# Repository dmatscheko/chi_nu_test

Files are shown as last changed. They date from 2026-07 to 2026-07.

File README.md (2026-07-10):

# χ_ν coherent-matter lift test

A pre-registered, falsifiable test of the OPH **χ_ν "coherent-matter lift"** claim —
the mechanism behind the OPH hoverboard concept — together with the audit work
that maps what the OPH corpus actually proves. The aim is to fix exactly what the
theory predicts **before** any data is taken, build the minimal self-reading device
the prediction requires, and let a pre-agreed decision rule — not either side's
prior — settle the outcome (detect / null / mundane / undefined).

Path shortcuts used throughout (`OPH:/`, `HOVER:/`, `ANS:/`) are defined in
Document A; `ANS:/` now points at this repo's own [`communication/`](communication/)
directory.

## Layout

| Directory | What lives there |
|---|---|
| [`OPH_PROOF_CHAIN_HOLES.md`](OPH_PROOF_CHAIN_HOLES.md) | **The adversarial audit companion, two passes** — an independent hole inventory of the chain's interpretation layer (first pass F1–F19 against v5; second pass F20–F29 + per-finding disposition audits against v6.1; both passes independently *confirm* the formal layer by environment-level axiom sweeps). v6.1 adopted the first pass; **v7 closed both passes' mathematics by theorem** (T27/T28/T29 + F20/F25/F26 closures) and swept the second pass's residue ledger; disposition tables in the proof chain's §11. |
| [`OPH_PROOF_CHAIN_PAPER.md`](OPH_PROOF_CHAIN_PAPER.md) | **The expository paper** — the whole machine-checked proof chain written as ordinary mathematics: statement, proof, "why", and a plain-language paragraph per result. Adds nothing to the Lean tree (the tree is the authority); exists so a physicist can read the chain end-to-end without opening a `.lean` file. |
| [`test/`](test/) | **The physics test** — the pre-registration ledgers that govern the experiment. |
| [`proof_chain/`](proof_chain/) | **The minimal-proof-chain work** — what the OPH corpus proves (incl. the `formal/` Lean project that machine-checks it), the audit exchange with the OPH side, and the satellite-repo audits. |
| [`build/`](build/README.md) | **The hardware** — Milestone-1 self-reading piezo PoC (build plan, rev-2 electronics + schematics, jig, firmware) and the Stage-0 calibration results. |
| [`communication/`](communication/) | **The Q&A with the OPH side** (`ANS:/`) — questions, replies, and the OPH-side PDFs. Absorbed from the former sibling repo on 2026-07-06. |

## The physics test (`test/`)

| File | Role |
|---|---|
| [`DOCUMENT_A_prediction_ledger.md`](test/DOCUMENT_A_prediction_ledger.md) | **Start here.** Imports the OPH math with verified provenance, records the agreed OPH-side inputs, discloses the conservation-law priors, and derives the falsifiable predictions + decision rule. Governs the outcome on its own. |
| [`DOCUMENT_C_run_matrix_and_error_budget.md`](test/DOCUMENT_C_run_matrix_and_error_budget.md) | The instrument, the run matrix (R-pre, ABBA, ACTIVE±/SHAM, blind controls), the error budget that fixes the detection floor, and the energy-budget logging. |
| [`DOCUMENT_B_critique_ledger.md`](test/DOCUMENT_B_critique_ledger.md) | Open-questions & credit ledger. Two live items — the ΔS-estimator bridge (G9) and the energy ledger (G10) — plus the disposition of the original critique (mostly closed) and what stands regardless of any outcome. |

## The minimal proof chain (`proof_chain/`)

| File | Role |
|---|---|
| [`OPH_CORE_MINIMAL_PROOF_CHAIN.md`](proof_chain/OPH_CORE_MINIMAL_PROOF_CHAIN.md) | **v7.** The minimal proof chain for the core OPH idea: machine-checked (Lean) → paper-side theorems → conditional → asserted/calibrated — with the conservation-law bounds on the χ_ν chain. Background for all three ledgers. |
| [`formal/`](proof_chain/formal/) | **The Lean 4 project that machine-checks the chain** — 38 modules; 1284 non-internal theorem/def declarations swept at the environment level (v10 filter; earlier counts used a wider filter), 0 `sorry`, 0 custom axioms (incl. an attributed copy of the OPH core with its three `sorry`s discharged; the v7 modules closing the adversarial audit's mathematics; the v9 worldline/crawl theorems T36/T37; and the v10 campaign T38–T41: the parity splitting, two-power universality, the lone diagonal observer). See its [`README`](proof_chain/formal/README.md) and the statement-by-statement audit in [`RESULTS.md`](proof_chain/formal/RESULTS.md). |
| [`AUDIT_RESPONSE.md`](proof_chain/AUDIT_RESPONSE.md) | The OPH side's 2026-07-06 response to our audit: validity grading per gap + the July paper pass that answers it. |
| [`AUDIT_RESPONSE_REVIEW.md`](proof_chain/AUDIT_RESPONSE_REVIEW.md) | Our verification of that response: all pin-cites checked, the P-derivation code executed (two-P finding), three refinements (R1 feed-forward carrier, R2 falsifiers ≠ energy ledger, §P). |
| [`formal_audits/`](proof_chain/formal_audits/) | Raw audits of the `dula/` satellite repos (verdict: not proof-chain-relevant; one reusable artifact, since ported). |

## How it fits together

**test/A** — what the theory predicts and how the result is decided ·
**test/C** — how it is measured · **test/B** — what stays open and what stands ·
**proof_chain/** — the standing of every imported claim and the audit exchange ·
**build/** — the device that produces the self-read receipt A requires ·
**communication/** — the primary-source Q&A the ledgers cite as `ANS:/`.

Version history lives in git: v0.1 ledgers (2026-06-02/03), the correction
pass ("corrections pass 1"), the v0.2 rewrite (2026-07-05), the audit exchange
and proof-chain v2 (2026-07-06), the v3/v4 `formal/` campaigns — the whole
chain machine-proven in one tree (2026-07-06) — the v5 campaign closing
the remaining open mathematics, incl. the D3 finite modular core and one
ledger erratum (2026-07-07) — and the v6 campaign settling the stride
conjecture (T25, the coprimality classification of two-column screens,
with the mirror lemma and the quotient lift as new tools) plus the
expository paper `OPH_PROOF_CHAIN_PAPER.md`, audited against the Lean tree,
and the v6.1 response to the adversarial audit `OPH_PROOF_CHAIN_HOLES.md`
(T26 — the cosmological-constant step; the G10 pricing convention named;
the F18 erratum table applied; disposition in the proof chain's §11)
(2026-07-07) — and the v7 campaign closing both audit passes' mathematics
by theorem (T27 Route A assembled; T28 the real-time modular flow; T29 the
channel bridge; the F20/F25/F26 closures; the ℤ₆ group isomorphism; the
theorem-grade energy anchors; the F22 evidence artifacts; the F21 residue
sweep) (2026-07-07). The former
`communication/` sibling repo's own history remains at
https://github.com/dmatscheko/hoverboard-experimental-precursor.

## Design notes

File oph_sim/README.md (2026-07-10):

# OPH proof chain — the simulation showroom (v2)

An interactive companion to [`../OPH_PROOF_CHAIN_PAPER.md`](../OPH_PROOF_CHAIN_PAPER.md)
(corpus **v10**, 2026-07-10: 38 Lean modules, 1284 swept declarations, 0 `sorry`,
standard axioms only) — and, new in v2, a **research instrument** pointed at the
chain's one remaining open mathematics item (the arbitrary-subset
classification). Sixteen scenes: the machine-checked core simulated live, the
conditional tower with every named hypothesis on the label, and a frontier wing
whose experiments have already produced five machine-testable conjectures
(C1–C5, [`FINDINGS.md`](FINDINGS.md) Part IV).

## Run

ES modules need a server (any static server works):

```sh
python3 -m http.server 8123 --directory oph_sim    # from chi_nu_test/
# → http://localhost:8123
```

Headless (same engine, no browser):

```sh
node node/selftest.mjs          # the 38-check theorem cross-check battery
node node/experiments.mjs quick # frontier experiments (E1–E10) → data/experiments.json
node node/experiments.mjs all   # + the multi-minute exhaustive jobs
```

## The scenes

**The cylinder**
- **Holography 3D** — the Rule-90 spacetime block as a cylinder; timelike /
  lightlike / sloped (now a theorem: T36) / spacelike screens; theorem badge +
  live 𝔽₂ rank on every slider; decode animation (green = local propagation,
  violet = determined-but-global, now the theorem T30a); ghost seeds; **Route A
  assembled** (T27) with rank/random schedules, T32's universal termination on
  the label, and the audit's exact stall witness (n=3, t=2) as a button.
- **Worldline lab (T36)** — draw ANY observer path; 1-Lipschitz paths get the
  theorem (sharp threshold, closure complete — the fan animation is the
  induction of `inferable_fan_of_pairs`); superluminal paths get the honest
  open-territory treatment, the kernel-checked (6,2)/(8,3)/(10,4) walls, and
  the teleporting observer's permanent ghost.
- **The crawl (T37)** — the gap-2 closure staged live: enclosed middle column →
  pair fans fill row 1 → row-0 hops of two wrap the odd ring (the ring dial
  shows the crawl crawling); even rings keep row 0 half-dark with the
  checkerboard ghost; the full T30+T37 distance trichotomy; the violet exhibit.
- **Phase maps** — live-computed landscapes: the jewel's exact staircase
  n = 2(t+1) (all green: T30b), the stride×ring gcd pattern with the violet
  T30a country, and the T36 worldline-invariance map (no deviations, by
  theorem).

**The open frontier**
- **Screen lab** — build arbitrary subsets; live rank/kernel/ghosts/closure;
  the **shadow atlas** (maximal ghost zero-sets = the classification itself)
  with the C1 even-ring parity law and C2 odd-ring rigidity checked live;
  Monte Carlo against the random-matrix baseline.
- **Beyond Lipschitz** — the recorded experiment suite (E1–E10): exhaustive
  capacity sweeps t ≤ 6, the power-of-two universality (C3, with the u-adic
  proof sketch), the teleport permanent-ghost law (C4), kink/slope-2/slack
  families, Lipschitz surjectivity (C5), tight-subset censuses — with live
  re-verification buttons that re-run the walls in your browser.

**Foundations** — Consensus (T0–T4, T12: Φ descent, the two-clerk race,
protection = Route A) and Toys (T5 width-3 witnesses, T8 layered sweep).

**The tower** (machine-checked mathematics downstream of named hypotheses) —
Hexacode (T19/T22, all enumerations live), Thermal time (T21/T28/T33 with the
KMS boundary strip drawn numerically), Dark sector (T15 with the exact Lean
phantom profile M_A, ρ_A), Collar & cage (T16/T35/T11/T10/T24 + the T29
channel-composite law computed live), Hypercharge & ℤ₆ (T13 in exact
rationals; the ℤ₆ wheel), Quorums (T23, the 3f+1 boundary).

**Meta** — The map (the graded ladder, scene↔theorem table, where mathematics
ends, the feedback-loop record) and Self-tests (the full battery in-browser).

## Fidelity contract

- One engine (`js/lib/f2.js`, `rule90.js`, `exact.js`) serves every scene, the
  battery, and the headless experiments. Definitions are transliterated from
  the Lean tree (`Inferable`'s exact rules, `colFamily`/`gapTube`/`slopeTube`/
  `pathScreen`, `ringDist`, the T24/T11 interval brackets, HexacodePort's 𝔽₄
  tables, Hypercharge's constraints in exact rationals).
- Every theorem badge is paired with an independent live computation; the
  38-check battery (`node/selftest.mjs` = Self-tests scene) is the acceptance
  gate. 38/38 at build time, in node and in the browser — five checks are
  anchored to the v10 theorems this simulation's own findings became
  (T38–T41; FINDINGS.md Part V).
- Discrete math is exact (bitmask/bitset 𝔽₂; int path n ≤ 30, Uint32Array
  beyond). Real-valued scenes use doubles against Lean's interval brackets.
- Part III/IV scenes simulate mathematics *inside* named hypotheses (SEE, MAR,
  L0–L7, D3, G9, G10…), never physics from consensus (T7's fence). The χ_ν
  experiment's expected outcome, per the chain's own grading: **NULL**.

## Files

```
index.html            the showroom shell (sidebar, stage, panel, banner)
js/app.js             scene registry / lazy router
js/lib/               f2.js · rule90.js · exact.js · ui.js · selftest.js
js/wing3d.js          the three.js wing (7 scenes)
js/scenes/            worldline · crawl · phase · subsetlab · frontier ·
                      hypercharge · qbft · selftest · map
node/                 selftest.mjs · experiments.mjs (headless drivers)
data/experiments.js(on)  the recorded frontier results (E1–E10)
three.min.js          three.js r147 (MIT, bundled)
```

See [`FINDINGS.md`](FINDINGS.md) for everything the simulation has taught the
theory so far — Parts I–III (v1: the items that became T30, T31, T36, T37) and
Part IV (v2: the shadow-atlas laws, power-of-two universality, the permanent
ghost, and the conjecture list C1–C5 handed to the next formal campaign).

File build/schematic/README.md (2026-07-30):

# Schematic generator

`schematic.py` turns a compact **path-based** text netlist into a real
electronic schematic SVG — proper symbols in **US/ANSI or IEC/European
style**, obstacle-avoiding orthogonal autorouting, automatic junction dots,
and **auto-sized sheets** (leave the size off `sheet` and the canvas fits
itself around the drawing, title and notes included). Zero dependencies
(pure Python 3).

The core idea: **the route is the statement.** Wires are written as `->`
paths, parts sit inline *on* the paths, and named nodes form junctions:

```
LEDC.p -> [res Rb "R_base" "1k"] -> BASE
BASE -> up 72 -> [npn Q1 "Q1" "S8050"].B
Q1.E -> OUT <- Q2.E
OUT -> [res Rd "100 Ω"] -> [piezo RING "Ring 0"] -> GND
```

Everything can be pinned manually (`at`, `right 120`, `(x,y)` waypoints) —
but nothing has to be: `at` is optional even for standalone parts and chips
(the first wired pin places them), statement order is free (whatever cannot
resolve yet is retried once the whole file is read), a sheet with no
absolute coordinates at all seeds itself at the origin, and with no hints
placement advances along the path while the router finds a clear Manhattan
route. Full reference: **[LANGUAGE.md](LANGUAGE.md)**.
One-of-every-symbol galleries: [examples/symbols_us.sch](examples/symbols_us.sch)
and [examples/symbols_iec.sch](examples/symbols_iec.sch) (same kit, both styles).
The previous (v1) engine, sources, and SVGs live in git history (the `v1/`
snapshot was removed from the working tree in the July 2026 cleanup).

The build diagrams are generated from the `.sch` sources here:

| Source | Output (in `../`) |
|---|---|
| `stage0_characterization.sch` | Stage-0 piezo characterisation rig (gen + scope) |
| `drive_stage.sch` | push-pull TX drive buffer |
| `tx_select.sch` | CD4066 TX-select (Stage 1b, full 3×3) |
| `peak_detector.sch` | RX Schottky envelope detector |
| `controller_power.sch` | power tree + I²C bus |
| `system_overview.sch` | block/flow diagram |
| `system_connected.sch` | whole instrument as one connected block graph |
| `full_instrument.sch` | full instrument as one real schematic, **built from the parts**: `import`s `drive_buffer` (drive_stage), `CD4066` (tx_select), `rx_channel` ×3 + `vbias` (peak_detector) |

## Regenerate

The canonical SVGs live in `../` (next to `electronics.md`, which embeds
them). The Makefile writes there:

```sh
make            # build all ../*.svg from the .sch sources
make png        # also drop ../*.png previews (needs rsvg-convert)
make nets       # per-net colour debug views -> ./*_nets.svg (never into ../)
make kicad      # KiCad 9 schematics + symbol library -> ./kicad/
make cleanup    # rewrite the .sch: drop params that don't change the SVGs
make clean      # remove the PNG previews, *_nets.svg and ./kicad/
```

By hand — every mode takes any number of `.sch` files (`make` is just the
first line); with several inputs `-o` names a directory:

```sh
python3 schematic.py *.sch -o ../
python3 schematic.py drive_stage.sch -o ../drive_stage.svg
```

## KiCad output (`--kicad`)

The same sheets also compile to a **real KiCad 9 schematic** — not a picture of
one: `--kicad` writes `<sheet>.kicad_sch` with every symbol it uses embedded in
the file, plus those symbols as a standalone `schpy.kicad_sym` library next to
it (so they can be picked from KiCad's own symbol browser and re-used by hand).

```sh
python3 schematic.py full_instrument.sch --kicad      # -> full_instrument.kicad_sch
python3 schematic.py *.sch -o kicad/ --kicad          # all of them + schpy.kicad_sym
make kicad
```

Open the `.kicad_sch` with KiCad's Schematic Editor (it offers to create a
project around it), or drop it into an existing project *under that project's
name* — `MILESTONE_1_build/MILESTONE_1_build.kicad_sch` — and it opens as that
project's root sheet. Nothing else is needed: no library has to be installed,
because the symbols travel inside the file.

**It really connects.** 10 px become 1.27 mm — KiCad's 50 mil grid, which is
also the raster these symbols were drawn on, so a resistor lead lands on
±3.81 mm exactly like KiCad's own `Device:R`. Three things make the connections
hold:

* **Snapped before routing.** The sheet is re-laid-out with parts, nodes and
  chip pin rows snapped onto the 50 mil raster *before* the autorouter runs, so
  the schematic lands on KiCad's grid and stays editable — drag a symbol and
  its wires come along. Snapping is a function of the coordinate, so equal
  coordinates stay equal and every row, column and alignment survives. If a
  sheet is drawn finer than that, the exporter falls back through 25 → 12.5 →
  5 → 2.5 mil until the circuit comes out **exactly** as the SVG draws it — the
  netlists are compared, and a sheet that cannot be reproduced is an error, not
  a silent rewiring. The grid it settled on is printed with each file.
* **Exact arithmetic.** Every coordinate is quantised to half a pixel before
  scaling, which makes each millimetre value an exact 4-decimal number, so a
  pin's absolute position (symbol origin + pin offset, the way KiCad adds them
  up) is bit-identical to the wire end drawn on it.
* **A real wire graph.** The routed polylines are re-cut before they are
  written: split at every point where another wire ends or a pin sits,
  overlapping duplicates dropped, junction dots where three or more segments
  meet, hair-off-axis runs pulled straight. KiCad joins wires at shared
  endpoints, not by "they look like they touch".

The result: **the netlist KiCad reads back is the netlist `--nets` prints**,
pin for pin — checked with `kicad-cli sch export netlist` on every sheet here.

What carries over:

| `.sch` | KiCad |
|---|---|
| `res`, `cap`, `diode`, `npn`, `opamp`, … | symbols in the embedded `schpy` library (`schpy:R`, `schpy:Q_NPN_BCE`, … — KiCad's own names and pin numbering, so swapping in `Device:R` later keeps the pins) |
| part `ref` + label / value | `R1` / `100 Ω` (auto designators; the source name is kept in a hidden `Sch` property, the label in `Description`) |
| `net GND`, `net +3.3V`, rail/gnd terminals | power symbols — one per terminal, all on the named net |
| `node NAME` | a net label on the wire (`_`-names stay plumbing, as in `--nets`) |
| `port` | a global label |
| `chip` / `block` | a per-sheet symbol: box, named pins, pin numbers 1..n in declaration order |
| `note` | text block under the drawing; `sheet` title → title block |
| `flow` arrows (system diagrams) | plain graphic polylines — they are drawings, not nets |

### Footprints

Every standard part gets a default footprint from KiCad's own libraries, so the
netlist is ready for the PCB step without a round of field-filling:

| part | footprint |
|---|---|
| `res` | `Resistor_SMD:R_1206_3216Metric` |
| `cap` | `Capacitor_SMD:C_1206_3216Metric` |
| `cap_pol` | `Capacitor_Tantalum_SMD:CP_EIA-3216-18_Kemet-A` (EIA-3216 = 1206) |
| `inductor` | `Inductor_SMD:L_1206_3216Metric` |
| `diode` `schottky` `zener` | `Diode_SMD:D_1206_3216Metric` |
| `led` | `LED_SMD:LED_1206_3216Metric` |
| `npn` `pnp` `nmos` `pmos` | `Package_TO_SOT_SMD:SOT-23` |
| `opamp` | `Package_SO:SOIC-8_3.9x4.9mm_P1.27mm` |
| `xtal` | `Crystal:Crystal_SMD_2012-2Pin_2.0x1.2mm` |
| `testpoint` | `TestPoint:TestPoint_Pad_D1.5mm` |
| `piezo` `battery` `switch` `button` `pot`, `chip`, `block` | left empty — those are the custom / mechanical ones (the rings, the LiPo, the modules) |

Override any of them per part with **`fp "Lib:Footprint"`**, which works on
standalone parts, inline parts, chips and `defchip` types alike:

```
res Rsda "Rp" "4.7 kΩ" fp "Resistor_SMD:R_0805_2012Metric" at 300,80
DRVOUT -> [res Rdd "R_drive" "100 Ω" fp "Resistor_THT:R_Axial_DIN0207_L6.3mm_D2.5mm_P10.16mm_Horizontal"] -> SW.INB
chip SW CD4066 fp "Package_SO:SOIC-14_3.9x8.7mm_P1.27mm" at DRVIN +460,0
```

The default also lands in the generated `schpy.kicad_sym`, so a symbol picked
from that library by hand arrives with its footprint already set.

The instrument's own parts carry their package in the `.sch` next to the
circuit, so the netlist is complete without touching KiCad:

| part | footprint | declared in |
|---|---|---|
| CD4066 | `Package_SO:SOIC-14_3.9x8.7mm_P1.27mm` | the `defchip` in `tx_select.sch` — every instance inherits it |
| ADS1015 | `Package_SO:TSSOP-10_3x3mm_P0.5mm` (TI's DGS body) | each sheet that draws it |
| MCP6022 ×3 | `Package_SO:SOIC-8_3.9x4.9mm_P1.27mm` | the `package AMP` line in `peak_detector.sch` |
| Xiao ESP32-C6 | `Seeed_Studio_XIAO_Series:XIAO-ESP32-C6-SMD` | `full_instrument.sch` (Seeed's own library; add the `.pretty` to KiCad's footprint table) |
| ring 0..2 | `Connector_JST:JST_PH_B2B-PH-K_1x02_P2.00mm_Vertical` | `peak_detector.sch` / `drive_stage.sch` — the two ring wires plug into the board |
| 1S LiPo | `Battery:BatteryHolder_MPD_BH-18650-PC` | `controller_power.sch`, `full_instrument.sch` |

`stage0_characterization.sch` has none: it is a bench rig (generator, scope
probes, loose rings), not a board.

### Real pin numbers and multi-unit packages

A generic symbol knows nothing about its package, so by default pins are
numbered 1..n in the order the symbol declares them. Two keywords fix that,
and neither changes the SVG:

* **`pins "…"`** gives the real package pin numbers, either by name
  (`pins "in+=3 in-=2 out=1 vcc=8 vee=4"`, the sheet's pin names or the KiCad
  symbol's, whichever reads better) or positionally (`pins "3,2,1,8,4"`). On a
  `defchip` it applies to every instance of that type.
* **`unit PKG [A]`** says this part is one unit of the physical package `PKG`
  (a name in the current namespace, so a `def` stamped three times gives three
  packages). Units of one package share a designator, a footprint and one
  multi-unit KiCad symbol — KiCad shows them as `U1A`, `U1B`. The optional
  letter fixes the order.
* **`package PKG "Device" [fp "Lib:Footprint"]`** names the physical part the
  units share (KiCad `Value`) and its footprint.

That is how the two `½ MCP6022` amplifiers in `peak_detector.sch` become one
SOIC-8 with the datasheet's pinout, while still being drawn as two op-amp
triangles in both the SVG and KiCad:

```
opamp A1 "A1 ½ MCP6022" "x21"  unit AMP A pins "in+=3 in-=2 out=1 vcc=8 vee=4" …
opamp A2 "A2 ½ MCP6022" "x5.7" unit AMP B pins "in+=5 in-=6 out=7 vcc=8 vee=4" …
package AMP "MCP6022" fp "Package_SO:SOIC-8_3.9x4.9mm_P1.27mm"
```

A unit's own value (`x21`) travels in a visible `Note` field, since KiCad's
`Value` belongs to the whole package. `tx_select.sch` and `full_instrument.sch`
carry the CD4066 and ADS1015 pinouts the same way (taken from KiCad's own
`4xxx` and `Analog_ADC` libraries).

Without `pins`, *Update PCB from Schematic* warns `No net found for component
U1 pad N (no pin N in symbol)` for every package pad the sheet does not draw —
which is also the honest warning for pins that really are unused (the CD4066's
fourth switch, the ADS1015's `AIN3`/`ALERT`, the Xiao's spare GPIOs). Declare
those pins in the `chip` block if you want them silent and reachable.

Two things are deliberately *not* claimed: there are no footprints (the
`Footprint` field is empty — that is the PCB step's job), and ERC will report
`power_pin_not_driven` for every power net, because nothing in a generated
sheet is a power *source*. Add a `PWR_FLAG` on each rail in KiCad, or silence
that rule, as usual. ERC also notes `lib_symbol_issues` until `schpy.kicad_sym`
is added to the symbol library table (Preferences → Manage Symbol Libraries),
and `endpoint_off_grid` on sheets that had to fall back to a finer grid —
harmless, the connections there are exact; set KiCad's grid to the size the
export reported and editing is comfortable again.

## Why a netlist instead of hand-drawn SVG

Every path endpoint is a **named pin** (e.g. `Q1.E`, `ADS.AIN0`). If a path
references a pin that does not exist, the tool **errors out** — so "do all
the paths connect?" is checked mechanically on every build. The diagrams are
also diffable and re-generatable, unlike hand-placed `<line>`s. Repetition is
first-class: a `def` block stamps a whole sub-circuit per `use`, and
`import "file.sch" [NAME …]` pulls just the `def`/`defchip` definitions out
of another sheet (its own drawing is skipped) — so every detail sheet doubles
as a library. `full_instrument.sch` contains no redrawn circuitry at all: it
imports the drive buffer from `drive_stage.sch`, the CD4066 from
`tx_select.sch`, and the amp+detector channel (stamped ×3 around one shared
bias divider) from `peak_detector.sch`.

## Colouring nets

1. **Meaningful colours (normal render):** declare a net colour once —
   `net GND #2166ac` — and end paths at its terminal (`-> GND`, `-> +5V`).
   The whole electrically-connected net inherits the colour. The build
   diagrams use +5 V `#e8412f`, +3.3 V `#a31515`, GND `#2166ac`, signals
   black. (For a coloured net without a terminal, put `color #hex` at the
   end of one of its paths.)
2. **Debug view (`--color-nets`):** auto-assigns a *distinct* colour per net,
   overriding everything — so a net showing two colours is broken and two
   nets sharing a colour are an accidental short:

```sh
python3 schematic.py controller_power.sch --color-nets   # -> controller_power_nets.svg
make nets
```

3. **Netlist print (`--nets`):** prints each electrical net as one sorted line
   (`REF.PIN` members, `<NET>` terminals, `(NAME)` nodes). Layout-independent —
   `diff` it before/after a re-layout to prove the electronics didn't change:

```sh
python3 schematic.py drive_stage.sch --nets
```

4. **Cleanup (`--cleanup`):** rewrites the given `.sch` files in place, deleting
   every position / path-length parameter (`at` clauses and offsets, exact
   moves, bare direction elements, aligned-move offsets) whose removal keeps
   the rendered SVG of **every** given sheet byte-identical — proof that the
   parameter was dead weight. Always pass the whole family so `def`s imported
   across files stay protected (that is what `make cleanup` does):

```sh
python3 schematic.py --cleanup *.sch
make cleanup
```

A net is the set of wires that electrically touch (coincident endpoints or
T-junctions). Plain crossings don't touch — a wire crossing another with no
dot keeps its own colour, visual proof it's a no-connect. The colour views
write to `*_nets.svg` *here* (never into `../`).

## Language cheat-sheet

See [LANGUAGE.md](LANGUAGE.md) for the full reference. The essentials:

```
sheet 1050x800 "Title"                  # canvas; note …  adds footnotes
sheet "Title"                           # no size -> auto-size, content centred
sheet "Title" iec                       # IEC/European symbols (default: us)
net +5V #e8412f "+5 V"                  # net colour + rail label, once

port DRV "Drive buffer OUT"             # no `at`: placed by its first wired use
chip T1 NE555                           # works for chips/blocks too
res  Rref "R_ref" "1 MΩ" a at RING.b +40,0 down   # or placed BY pin a, vertical
res  Rp "4.7 kΩ" fp "Resistor_SMD:R_0805_2012Metric"   # KiCad footprint override
rail F1 "+5V" at 300,80                 # standalone net terminal (label = net)
gnd  G1 at 300,400                      # same for ground (net GND)

DRV.p -> [res Rd "100 Ω"] -> SW.INB     # parts live ON the route
RING.b -> right 40 -> down -> [res Rr "1 MΩ"] -> down 30 -> GND   # hang + ground
Q1.E -> OUT <- Q2.E                     # runs meet: node at the midpoint + dot
[npn Q1].B -> BASE <- [pnp Q2].B        # pair-meet: spreads ±80 around the node
GPIO6 -> right to Rsda.b -> _SDA -> SDA # thread node _SDA into the line …
Rsda.b -> _SDA                          # … and tap it by name (preferred)
(382,85) -> (1250,85)                   # a bus (waypoints are literal)
Rsda.b -> down 68                       # tap down ONTO a line below (sketch)
Ra.b -> right to XIAO.V5 +50            # aligned tap: right only, to V5's x +50

chip ADS at 740,250 200x180 "ADS1015" "I²C 0x48"   # or defchip + include
  left  AIN0 AIN1 AIN2 AIN3
  right VDD SDA SCL
end

def channel(hot, ring)                  # define once …
  hot -> down -> [piezo RNG ring lpos left] -> down 40 -> GND
end
use channel ch0(H0, "Ring 0")           # … stamp: parts become ch0.RNG, …
node OUT                                # declare (unplaced) so a use can bind it
import "peak_detector.sch" rx_channel   # defs/defchips only, sheet skipped

block XIAO "Xiao ESP32-C6" "l1|l2" at 500,100 200x96 accent   # system diagrams
  bottom DRIVE RESET I2C
end
flow XIAO.DRIVE -> down -> BUF.e "DRIVE (GPIO2)" dash
```

Pin names by type:

| Type | Pins |
|---|---|
| `res` `cap` `cap_pol` `inductor` `piezo` `xtal` `switch` `button` | `a` `b` |
| `pot` | `a` `b` `w` (wiper) |
| `diode` `schottky` `zener` `led` | `a` (anode) `k` (cathode) |
| `npn` | `B` `C` `E` — `pnp`: `B` `E` `C` |
| `nmos` `pmos` | `G` `D` `S` |
| `opamp` | `in+` `in-` `out` `vcc` `vee` |
| `battery` | `+` `-` (aliases `a` `b`) |
| `gnd` / `rail` / `port` / `testpoint` | `p` |
| `chip` / `block` | the pins you declare (`block` also: `n s e w c`) |

Orientation words `up/down/left/right` set a part's a→b axis; `mirror` flips
it; `lpos up|down|left|right` moves the label. Junction dots appear only
where ≥3 conductor directions meet; plain crossings get **no** dot. Autorouted
wires leave/enter each pin with a straight 10 px run along the pin's direction
(`escape N` adjusts it; 0 disables).

Node naming: plain names (`BASE`, `OUT`) are circuit signals and appear in
`--nets`; a leading underscore (`_SDA`, `_V33`) marks a pure trace point —
hidden from `--nets` like the tool's own anonymous nodes, and never
confusable with a part ref or a net terminal.

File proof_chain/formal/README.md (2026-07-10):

# `formal/` — machine-checked closure work for the OPH minimal proof chain

| | |
|---|---|
| Date | 2026-07-06 (v3 + v4 campaigns) + 2026-07-07 (v5 + v6 + v7 + v8 campaigns) + 2026-07-09 (v9 campaign) + 2026-07-10 (**v10** campaign) |
| What | A standalone Lean 4 + Mathlib project that (v3) formalized the `OPH_CORE_MINIMAL_PROOF_CHAIN.md` §7 targets and the "open jewel", (v4) **absorbed the OPH Lean core itself into this tree with its three `sorry`s discharged** and formalized the remaining mathematically-formalizable links: the L2.4 algebra (hypercharges + ℤ₆), the D5 Einstein-branch algebra, the dark-sector mathematics (L2.7/L2.8 + the L2.11 FTC step), the collar-gate skeleton (L2.6), the ΔS-bridge definition side (P5/L2.12), the §7.6 stretch item (general Rule-90 decodability: boost invariance + the parity obstruction), and the hexacode MDS toy (§9), and (v5) **settled the odd-cylinder gap-2 threshold** (the §7.6 item v4 left open — the complete parity classification), **built the D3 finite modular core** (retiring "the one link with no isolable finite-mathematics core"), closed the hexacode weight distribution, machine-checked the run-matrix conversion constants (finding and fixing one ledger erratum), and formalized the corpus appendix's QBFT safety theorem (finding a boundary caveat), and (v6) **settled the stride conjecture** — T25, the coprimality classification of two-column screens (`gcd(g,n) = 1 ∧ n ≤ 2(t+1)` ⟺ capacity), via the new mirror lemma and quotient lift — plus the separation-statement clauses and the `EdgeRepairable`-strictness witness, and (v7) **closed the adversarial audit's remaining mathematics**: T27 — Route A *assembled* (local tube-preserving transactional decode-repair + `H_B` + the sharp `H_fib` jointly on the T9′ carrier, with both impossibility negatives and the stall witness machine-checked, closing F2); T28 — the real-time modular flow (`H = −log ρ` exists; `σ_z` is a ⋆-automorphism group with the textbook KMS boundary condition; `σ_i = Δ_ρ`; Hamiltonian-implemented uniqueness `e^{−K} = c·ρ`, closing F9 finite-dimensionally); T29 — the channel bridge (one indexed family, both counters, composite Tier-B1 law, closing F11); the ℤ₆ kernel as a **group isomorphism** (F10c); and the theorem-grade energy anchors bracketing the G10-convention (F15). **The whole chain lives, machine-proven, in this one directory tree.** The **v8 campaign** (same day, verification pass + simulation feedback + leftovers): independently re-verified the v7 modules (read + build + 1199-declaration environment sweep), then closed T27's named leftover — **T32, arbitrary-schedule termination** (`decodeStep_wellFounded`: the decode dynamics is strongly normalizing under EVERY scheduler; the rank stratification itself is the lexicographic potential) — and T28's named leftover — **T33, Skolem–Noether for the matrix algebra** (`algEquiv_matrix_inner`: every `ℂ`-algebra automorphism is inner; `kms_algEquiv_structure`: any KMS-satisfying automorphism IS the modular map with conjugator `c·ρ`) — plus the F24 residue — **T35, `TriangulatedSphere`** (the twelve-port count's three assumed equations are now theorems of an actual surface structure; kernel-checked icosahedron instance) — and two theorems surfaced by the simulation companion (`oph_sim/FINDINGS.md`): **T31, the readout trichotomy** (`readout_trichotomy` + `tubeData_surjective_iff`: ghosts/bijective/unrealizable split exactly at the threshold — above it EVERY tube reading is realizable, at it the readout is a bijection, below it empty fibers exist ⟺ `n < 2(t+1)`; Route-A corollaries `exists_unrealizable_tube_iff`, `no_stall_at_threshold`) and **T30, the local-decodability phase boundary** (`spread_screen_inferable_iff`: screens with pairwise column distance ≥ 3 admit ZERO local constraint-propagation inferences at any horizon; `adjacent_closure_complete`: the adjacent tube's propagation closure is the whole block at the sharp threshold; `violet_exhibit`: `n=8, g=3, t=3` is machine-checked as determined-but-locally-dark). **T34-lite**: the sloped-screen *definition* is now formal (`slopeTube`, floor convention, provably slope-0 = T9's tube), the failure half is a theorem at every slope, and slopes 1/2, 1/3, 2/3 have kernel-checked threshold instances — the general positive half remained the named open conjecture. The **v9 campaign** (2026-07-09) closed it: **T36 — the Lipschitz worldline theorem** (`Rule90Lipschitz.lean`): every 1-Lipschitz worldline pair-screen is *completely locally decodable* at the sharp threshold (`pathScreen_closure_complete` — T30b extended from the static observer to every causal worldline, zigzags and negative slopes included), hence an information set **iff** `n ≤ 2(t+1)` (`pathScreen_isInformationSet_iff`); corollary `slopeTube_isInformationSet_iff` — **the slope conjecture (holes-audit F6) is CLOSED**, every rational slope `0 ≤ p/q ≤ 1`, every `n`, `t`, base point, sharp. The non-Lipschitz regime is machine-checked to be genuinely wild (complete order-sensitive classification at `(6,2)` — `pairScreen_class_6_2`; all `8^4` paths decode at `(8,3)`; the slope-2 line and late jumps FAIL at exact capacity at `(10,4)`), which is the precise delimitation of the one remaining open mathematics item (arbitrary subsets). And **T37 — the gap-2 crawl classified** (`Rule90Crawl.lean`): T30's named leftover closed — on odd rings at the sharp threshold the distance-2 screen's propagation closure is the entire block (the simulation's crawl, made into a proof through T36's general fan with *inferred* anchors), on even rings it never reaches the seed row; with T30, local decodability of two-column screens is classified at every ring distance. The **v10 campaign** (2026-07-10, driven by the `oph_sim` v2 findings): **T38 — the parity splitting** (`Rule90Parity.lean`): finding R1 formalized — on even rings the spacetime block is two non-interacting Rule-60 sectors (with the bridge `traj x i j = rule60^[2i] x (j−i)` and the half-ring conjugacy `sectorTrace_succ`), and an ARBITRARY cell set fails ⟺ a nonzero single-parity ghost is dark (`not_isInformationSet_iff_single_parity_shadow` — the containment half of conjecture C1, unconditional); **T39 — two-power universality** (`Rule90TwoPower.lean`): conjecture C3 closed — on `n = 2^k` EVERY worldline pair screen decodes iff `n ≤ 2(t+1)`, teleports included, by nilpotency of Rule 60 and the all-ones funnel; **T40/T41 — the lone diagonal observer** (`Rule90Diagonal.lean`): a lightlike diagonal reading ONE cell per row is an information set on odd rings iff `n ≤ t+1` — the first *counting-tight* screen family — never on even rings, where two diagonals decode iff their bases have opposite parity, sharp at any offset. |
| Toolchain | `leanprover/lean4:v4.29.1`, Mathlib pinned to the **same revision** as `observer-patch-holography/LEAN` (`5e932f97…`), so results transfer 1:1 (upstreaming = file move + namespace) |
| Status | **Builds clean. 0 `sorry` (including the imported core — its three source `sorry`s are discharged here), 0 custom axioms, no `native_decide`.** Every headline theorem ends with `#print axioms`; all report at most `[propext, Classical.choice, Quot.sound]` |
| Build | `cd formal && lake exe cache get && lake build` (first run downloads the Mathlib cache) |
| Provenance | Files under `OPHProofChain/Core/` are attributed copies from `observer-patch-holography/LEAN/` (headers state exactly what changed; all modifications carry `[formal-v4]` tags). `HexacodePort.lean` is an attributed port from `dula/prime-inertia-engine` (header; the v5 weight-distribution section is native, `[formal-v5]`-marked). `Rule90Stride.lean` and `RepairHypotheses.lean` are native `[formal-v6]` modules; `RouteA.lean`, `ModularFlow.lean`, and `ChannelBridge.lean` are native `[formal-v7]` modules; `Rule90Readout.lean`, `Rule90Propagation.lean`, `Rule90Slope.lean`, and `SimplicialSurface.lean` are native `[formal-v8]` modules (the first three crediting `oph_sim/FINDINGS.md` for surfacing the statements); `Rule90Lipschitz.lean` and `Rule90Crawl.lean` are native `[formal-v9]` modules; `Rule90Parity.lean`, `Rule90TwoPower.lean`, and `Rule90Diagonal.lean` are native `[formal-v10]` modules (crediting `oph_sim/FINDINGS.md` — finding R1, conjecture C3, probe F4 — for surfacing the statements). `ConsensusSafety.lean` formalizes (with attribution) the corpus appendix `paper/appendix_B_bft_qecc_extensions.tex`. Everything else originates in this repo. |

## What was closed, in one table

| Module | Result | Was (proof chain v2) | Is now |
|---|---|---|---|
| [`QuotientRepair.lean`](OPHProofChain/QuotientRepair.lean) | **P1** — the full quotient repair operator package: presentation `(Σ,Γ,q,Q,C_Q,B,μ,𝖠,≺_𝖠)` with `H_B, H_↓, H_◇, H_comp`; `locRep` (least enabled transaction); `globalRepair` total, valued in `C_Q`, boundary-preserving, idempotent, fixed exactly on `C_Q`; **schedule independence** via a self-contained Newman's lemma; `World`, `world_is_fixedPt`, `repair_respects_gauge` (3 forms); a real demo instance; and the separation package `symmetricPair_not_locallyConfluent` + `symmetricPair_descends` + `symmetricPair_normalForm_iff` (`[formal-v6]`) showing `H_◇` does genuine work — the symmetric witness honestly satisfies `H_↓ ∧ H_comp` (with `H_B` vacuous) yet is not locally confluent | paper-side theorem (tex 433–610, 1143–1170); Lean core carried 3 `sorry`s for exactly this machinery; `PROOF_INDEX.md` at 0 % of Prop 4.2 | **machine-checked** — every Def 4.1 / Prop 4.2 gap row of `PROOF_INDEX.md` has a corresponding sorry-free theorem here (mapping table in the module docstring) |
| [`NotEinsteinComplete.lean`](OPHProofChain/NotEinsteinComplete.lean) | **P2** — `bare_consensus_not_einstein_complete`: two geometric extensions of the *same* (real, non-degenerate) consensus reduct with opposite Einstein truth values; no predicate of the reduct decides the Einstein equation | paper-side negative theorem (tex 227–271) | **machine-checked** (definability separation, matching the paper's own proof) |
| [`LayeredCarrier.lean`](OPHProofChain/LayeredCarrier.lean) | **P3** — layered functional boundary carrier: `extend` (=`E(b)`), staged sweep, `H_B` (`sweep_restrictB`), reconstruction (`sweep_eq_extend`), `H_fib` singleton fiber (`hfib_singleton`), presentation-free reconstruction corollary, genuinely multi-edge demo | paper-side theorem (tex 1225–1364), feed-forward class (review R1) | **machine-checked**, same honest scope (feed-forward class — the QECC-strength content lives in the next row) |
| [`Rule90Cylinder.lean`](OPHProofChain/Rule90Cylinder.lean) | **The open jewel (§7.2 / R1), proven sharp**: on the Rule-90 `n`-cylinder run for `t` steps, the width-2 timelike tube is an information set **iff `n ≤ 2(t+1)`** (`tube_information_set_iff`) — the sideways-lightcone bound and the raw counting bound coincide, so the timelike screen **saturates the information bound**. Plus: width-1 columns fail at *every* horizon (mirror-kernel construction, `n ≥ 3`; nilpotency, `n = 2`), and **no proper spacelike subset** of the initial row ever works — a sharp timelike/spacelike asymmetry | named open (review R1: "remains the open jewel"); only the width-3 one-step toy existed | **machine-checked, with a sharp iff** — strictly stronger than what was asked (the ask was sufficiency on some family) |
| [`LambdaConstancy.lean`](OPHProofChain/LambdaConstancy.lean) | `[formal-v6.1]` **T26 — the cosmological-constant step**: `einstein_equation_with_constant` — null-cone matching at every point of a connected discrete chart + the contracted Bianchi identity + local stress conservation (both **named** hypotheses) ⟹ `F = κT + Λη` with one constant `Λ`; `lambda_not_constant_without_connectivity` shows connectivity is load-bearing | the adversarial audit's F8: the pointwise λ of `jacobson_step` was called "the cosmological constant" one (written, unformalized) Bianchi step early | **machine-checked** — T14 now ends at the Einstein equation, with the geometry/physics inputs named |
| [`RepairHypotheses.lean`](OPHProofChain/RepairHypotheses.lean) | `[formal-v6]` **The T12 hypothesis lattice, closed**: `rule90_edgeRepairable` + `rule90_not_frustrationFree` + `edgeRepairable_strictly_weaker` — the width-3 carrier witnesses that `EdgeRepairable` (T12's completeness hypothesis) is **strictly** weaker than `FrustrationFree`, so canonical completeness provably covers carriers where no frustration-free operator exists | the docstrings asserted "strictly weaker" prose-only | **machine-checked** (native module; `Core/` copies stay verbatim) |
| [`CarrierBridge.lean`](OPHProofChain/CarrierBridge.lean) | The jewel in the Lean core's own vocabulary: `rule90Cylinder n t` (a `(t+1)`-patch, `t`-edge `OPHCarrier`), `H_fib` discharged for the tube boundary in the exact `boundary_fiber_observer_unique` binder form, sharpness, width-1 failure, and proof that the tube is strictly coarser than `obsMap` (no definitional endpoint) | R1: "proper-subset boundaries on carriers with code redundancy — remains the open jewel" | **machine-checked** on a genuinely multi-edge carrier |
| [`EnergyCage.lean`](OPHProofChain/EnergyCage.lean) | **G10, theorem side**: the ABBA cycle identity (`cycleWork = toggleCost q₁ − toggleCost q₂`), `no_free_toggle` (zero toggle ledger ⇒ zero extractable work — else perpetual motion), ledger lower bound; **design-point arithmetic** machine-checked: `σ_ph ∈ (11.6, 11.8) kg/m²` per `10⁻⁹`, toggle transaction `∈ (3.49, 3.52) MJ` at 56 gf | §5 prose + hand arithmetic; "valid as an external physics obligation" (their grade) | **machine-checked** (the *cage*; the force law itself, L2.11, remains open — this prices it) |
| [`PBranches.lean`](OPHProofChain/PBranches.lean) | **The two-P finding (review §P) + the L2.10 value**: `Ppub = φ + √π/137.035999177 = 1.630968209403959…` digit-checked from scratch (`√5`, 20-digit `π` bounds); solver root differs by `3.8–4.0×10⁻⁶`; `χ_can = e^(−P/24) = 0.9343006…` via a 6-term Taylor sandwich with explicit remainder; branch discrepancy `Δχ ∈ (1.4, 1.6)×10⁻⁷` — real in the 8th digit, immaterial for the experiment | prose adjudication + executed code | **machine-checked arithmetic**, with the CODATA provenance carried in the definition (nothing here derives α — see module docstring) |
| [`ScalarResponse.lean`](OPHProofChain/ScalarResponse.lean) | **P4, form half (linear-algebra core)**: under SEE (one-generator register), every linear response is `S = c·η ↦ χ·c`, and no second susceptibility exists | paper-side theorem under SEE (screen tex 817–864) | LA core **machine-checked**; SEE itself stays the named physical hypothesis (unchanged, on purpose) |
| [`Rewriting.lean`](OPHProofChain/Rewriting.lean) | Self-contained Newman's lemma + unique normal forms (independent re-proof, compatible with the core's `AbstractRewriting.lean`) | (infrastructure) | machine-checked |

## The v4 campaign, in one table

| Module | Result | Was (proof chain v3) | Is now |
|---|---|---|---|
| [`Core/Primitives.lean`](OPHProofChain/Core/Primitives.lean) (+ `Core/AbstractRewriting.lean`, `Core/Rule90.lean`) | **The OPH Lean core, imported and discharged.** `localRepair` := the canonical frustration-free snap operator (fires iff a broken incident edge exists ∧ the patch can satisfy all its interfaces; `Classical.choose` state); `Repair` := the declared-order least-firing-site iterate (Route B on the original carrier); `repair_respects_gauge` **proved** (everything the operator reads factors through `obsMap`). Bonus: the file's own `Termination` + `LyapunovDescent` proved for **every** carrier, `Completeness` under the named `EdgeRepairable` (weaker than frustration-free), the file's own `Confluence` **refuted** on `demoCarrier`, and `localRepair = demoLR` there (anti-degeneracy) | the three documented `sorry`s lived in the OPH team's repo; `QuotientRepair.lean` proved their content in quotient form; "upstreaming is mechanical; their call" | **the whole chain machine-proven in this one tree, 0 `sorry`** — the copies are attributed, all modifications `[formal-v4]`-tagged |
| [`Hypercharge.lean`](OPHProofChain/Hypercharge.lean) | **L2.4 algebra, half 1**: Yukawa closure + `[SU(2)]²U(1)` + gravitational anomaly ⇒ the hypercharge ratios (any `N`, over `ℚ`); `[SU(N)]²U(1)` implied by Yukawa alone; `[U(1)]³` cancels **identically** on the ray; `Q(ν_L) = 0` pins `Y_Q = 1/(2N)`; `N = 3` ⇒ the exact SM lattice, uniquely | "real algebra" (prose grade), unformalized | **machine-checked** |
| [`CenterZ6.lean`](OPHProofChain/CenterZ6.lean) | **L2.4 algebra, half 2**: in `ℤ₃ × ℤ₂ × ℝ/ℤ`, the subgroup acting trivially on all six SM multiplets is **exactly** `⟨(1,1,1/6)⟩ ≅ ZMod 6` — since v7 as a genuine **additive-group isomorphism** (`kernelAddEquiv`, audit F10c), not merely a bijection; the generator has order 6; charges match `Hypercharge.smAssignment` | compact paper Prop `prop:z6`, prose | **machine-checked** (MAR — the *selection* of the package — stays the named physical hypothesis) |
| [`EinsteinBranch.lean`](OPHProofChain/EinsteinBranch.lean) | **L2.3 linear-algebra core (D5)**: the rest-frame arithmetic of `thm:einstein`; the timelike polynomial upgrade (symmetric tensor vanishing on all future unit timelike directions is 0 — finite witnesses, no analysis); the classic null-cone lemma (`B = λη`, the Jacobson equation-of-state step); the packaged conditional: variational identities (named physics) ⇒ full tensor Einstein equation | conditional tex chain (D4–D5), algebra unformalized | **LA core machine-checked**; entropy stationarity / small-ball / area-variation identities stay named hypotheses |
| [`DarkSector.lean`](OPHProofChain/DarkSector.lean) | **L2.8 + L2.7 mathematics**: activation law well-definedness, monotonicity, Newtonian + deep-MOND limits (exact `√(a_eff g_b)` scaling), BTFR, the rare-event `(1−μ/m)^m → e^{−μ}`; the phantom-density identity as pure bookkeeping over any linear divergence; the exact point-source profile `M_A′ = 4πr²ρ_A` + positivity; the thin-device FTC step `F = g²/(4πG)·A·χ·ΔS` | compact conditional derivation + Correction Audit, prose | **mathematics machine-checked**; Poisson-counting premises + flux closure + the lab response law stay named physics |
| [`CollarGate.lean`](OPHProofChain/CollarGate.lean) | **L2.6 skeleton**: finite-slice collar model; slice-wise unbiasedness ⇒ `λ_collar = e^(−P/24)` exactly (the gate theorem's own proof); the Jensen band `e^(−P/24) ≤ λ ≤ 1` under the mean condition; `χ_can = λ_collar` forcing; the `24 = (P/4)/6`-per-class and `2×12`-oriented-slots bookkeeping; discrete Gauss–Bonnet: any all-triangle sphere has total defect 12 ⇒ exactly 12 unit-defect ports | conditional theorem with explicit gate (L1–L7) + receipts, prose | **skeleton machine-checked**; the L1–L7 operator-algebra clauses stay named physics |
| [`DeltaSBridge.lean`](OPHProofChain/DeltaSBridge.lean) | **P5 / L2.12 definition side**: the finite coherent-source generator (Def B.5) as a formal object; the exact increment identity `(𝓛 𝒩)(q) = S·A(q)` (Theorem B.7) + positivity + non-saturation; the Tier-B response-law shape | "definition side closed on paper; **no formal object to port yet**" | **the formal object exists and the identity is machine-checked**; G9 (the numerical record-ΔS → gravity-ΔS map) stays open — a null bounds only `χ·ΔS` |
| [`Rule90Decoding.lean`](OPHProofChain/Rule90Decoding.lean) | **The §7.6 stretch item**: general `IsInformationSet` framework (vanishing-form equivalence, decidability, universal counting bound, monotonicity); T9 restated; **NEW — boost invariance**: the *lightlike* width-2 screen is an information set iff `n ≤ 2(t+1)`, the same sharp threshold (one-sided double-speed sweep); **NEW — adjacency is load-bearing**: the gap-2 screen on even cylinders fails at every horizon (explicit alternating-seed kernel); decided odd-`n` and boundary instances | "generalize T9 … a full decodability classification" (stretch, open) | **width-2 geometry settled completely; arbitrary subsets now a decidable predicate** (full weight-distribution classification honestly still open) |
| [`HexacodePort.lean`](OPHProofChain/HexacodePort.lean) | **The §9 suggestion**: the `dula/` hexacode ported (attributed); its own open list closed in Lean — minimum distance 4 (⇒ `[6,3,4]₄`, MDS), Hermitian self-duality — and the OPH payoff: **every 3-subset of coordinates is an information set** (proved from `d = 4`, not by enumeration) | "one `decide` lemma away" (suggestion) | **machine-checked**; the geometry-blind MDS extreme next to Rule-90's geometry-sensitive screens |

## The v6 campaign, in one table

| Module | Result | Was (proof chain v5) | Is now |
|---|---|---|---|
| [`Rule90Stride.lean`](OPHProofChain/Rule90Stride.lean) (new, native) | **T25 — the coprimality classification of two-column screens**: `gapTube_isInformationSet_iff` — the screen `{j₀, j₀+g} × [0,t]` is an information set **iff `gcd(g,n) = 1` and `n ≤ 2(t+1)`**. Built on the **mirror lemma** (`mirror_of_column_dark`: a dark column forces mirror symmetry about itself — the defect trajectory is Rule-90 in displacement space, dark on an adjacent pair) and the **quotient lift** (`traj_comap`: reduction mod `gcd` is a covering; both columns land on one dark quotient column). T9-sufficiency, T20, and the width-1 negatives re-derived as the `g = 1, 2, 0` corollaries; boundary `decide`s at `(8,3,3)`/`(8,3,2)`/`(9,3,4)` | §7 item 6's *conjecture* ("capacity iff `gcd(g,n) = 1`", from T20's mechanism) | **machine-checked, sharp, complete** — and stronger than conjectured: full adjacent capacity at the same threshold for every coprime stride |
| [`QuotientRepair.lean`](OPHProofChain/QuotientRepair.lean) (extension, `[formal-v6]`) | `symmetricPair_descends` + `symmetricPair_normalForm_iff` — the separation witness satisfies `H_↓` and `H_comp` honestly (`H_B` vacuous on the boundary-free carrier) | the separation statement's non-confluence half only | **all clauses machine-checked** (`normalForm_iff` axiom-free) |
| [`RepairHypotheses.lean`](OPHProofChain/RepairHypotheses.lean) (new, native) | `edgeRepairable_strictly_weaker` — the width-3 carrier is `EdgeRepairable` but not `FrustrationFree` | "strictly weaker" asserted in docstrings/docs, prose-only | **the strictness is a theorem** — T12's completeness provably covers non-frustration-free carriers |

## The v7 campaign, in one table

| Module | Result | Was (proof chain v6.1) | Is now |
|---|---|---|---|
| [`RouteA.lean`](OPHProofChain/RouteA.lean) (new, native) | **T27 — Route A assembled** (holes-audit F2): local decode transactions (single-cell writes, edge-bounded windows, formula-mismatch trigger) under a declared responsibility roster (budgets `R = min t (n−2)`, `L = (n−2)−R` — a roster with both budgets `≤ t` exists **iff** `n ≤ 2(t+1)`, the jewel's own threshold); liveness (`pass_spec`), `H_B` (`decodeStep_tube`), **observer uniqueness in equality form under any schedules** (`routeA_observer_uniqueness`), completeness ⟺ fiber realizability (`routeA_world_consistent_iff`), the bundle with the sharp `H_fib` (`routeA_assembled`); **negatives**: `rule90CylinderOPH_no_frustrationFree_repair` (∀ n ≥ 1, t ≥ 1), `canonical_repair_stalls` (the audit's exact witness), `stallRecord_tube_unrealizable` (its fiber has no consistent record — the stall is logic) | F2 acknowledged in place; "the concrete v7 formalization target"; stall witness "checkable by hand, not in tree" | **machine-checked, jointly, on one carrier — the composition the program's flagship story always claimed** |
| [`ModularFlow.lean`](OPHProofChain/ModularFlow.lean) (new, native) | **T28 — the real-time modular flow** (holes-audit F9): `exists_modularHamiltonian` (`H = −log ρ`, spectral construction); `flow` = `e^{izH}(·)e^{−izH}` for all complex `z` — group law, ⋆-automorphisms, unitary propagators at real times, norm-continuity, state invariance; **`flow_I_eq_modular`** (`σ_i = Δ_ρ` — the analytic anchor); **`kms_boundary`** (the textbook KMS condition with real time inside); **`hamiltonian_kms_unique`** (`e^{−K} = c·ρ`, real `c > 0`) | "the real-time statement named as open (§7 item 7)"; T21's map "iterated over integers" | **the clock is a clock, machine-checked**; named leftover: Skolem–Noether (beyond Hamiltonian-implemented flows); BW identification stays physics |
| [`ChannelBridge.lean`](OPHProofChain/ChannelBridge.lean) (new, native) | **T29 — the channel bridge** (holes-audit F11): `Channel` (one finite indexed family, both panels), `toRegister`/`toSlices`, **`same_family := rfl`**, `bridge_gate`, **`channel_composite`** (`λ_collar·(𝓛𝒩)(q) = e^{−P/24}·S·A(q)`), non-vacuity | "the same counter" was prose across two disjoint modules; v6.1 demoted the wording | **the identification is definitional inside one structure; the composite Tier-B1 law is a theorem**; residues = the named channel identification + G9 |
| [`CenterZ6.lean`](OPHProofChain/CenterZ6.lean) (extension, `[formal-v7]`) | `phase_add/zero/neg`, `kernelSubgroup`, **`kernelAddEquiv : ZMod 6 ≃+ kernelSubgroup`** | set bijection + `addOrderOf g0 = 6` (audit F10c: "assemble-able but never assembled") | **the group isomorphism the documents quote** |
| [`EnergyCage.lean`](OPHProofChain/EnergyCage.lean) (extension, `[formal-v7]`) | `cycleWork_self` (fixed-position ⇒ zero forced entry), `bench_cycle_work_value` (`(0.549, 0.550) J` per metre), `mass_energy_value` (`(5.03, 5.04)×10¹⁵ J`), **`anchor_ordering`** (floor < G10-convention < ceiling, strict) | the anchors stated in prose (v6.1's F15 fix) | **interval arithmetic — the audit's "seven orders above, nine below" is now a theorem** |
| [`EnergyCage.lean`](OPHProofChain/EnergyCage.lean) (extension 2, `[formal-v7]`) | **the cage slogan at full generality** (holes-audit F25): schedules as lists of moves/toggles; the first law along any schedule; **`no_schedule_beats_the_ledger`** (closed schedules: work = net ledger ≤ toggles·ε) | slogan proven for the ABBA cycle only | **every schedule covered; ABBA is the two-toggle case** |
| [`CarrierBridge.lean`](OPHProofChain/CarrierBridge.lean) (extension, `[formal-v7]`) | **`hfib_strictly_weaker_than_informationSet`** (holes-audit F20): the row-1 readout of `rule90Cylinder 3 1` satisfies the `H_fib` binder verbatim while two distinct consistent records share it | the audit's counterexample, compiled out-of-tree | **in-tree; the paper's front-door "exactly" corrected to the true direction** |
| [`LambdaConstancy.lean`](OPHProofChain/LambdaConstancy.lean) (extension, `[formal-v7]`) | **`lambda_constant_symm`** (holes-audit F23): constancy under symmetric-closure connectivity | forward root-reachability only (ℤⁿ-style charts uncovered) | **covered** |
| [`RepairHypotheses.lean`](OPHProofChain/RepairHypotheses.lean) (extension, `[formal-v7]`) | **`frustrationFree_properly_within_edgeRepairable`** (holes-audit F29(v)): the proper class inclusion, packaged | a one-meta-step gloss over a conjunction | **packaged theorem** |
| [`evidence/`](evidence/) (new) | **the computational-evidence artifacts** (holes-audit F22): `decodability_checker.py` + committed output tables — the stride sweep (`n ≤ 28`) and the slope sweep (`n ≤ 20`, floor convention **defined**) | two "machine experiment" claims with no artifact in the repo | **receipts committed; both claims re-verified** |

## The v5 campaign, in one table

| Module | Result | Was (proof chain v4) | Is now |
|---|---|---|---|
| [`Rule90Decoding.lean`](OPHProofChain/Rule90Decoding.lean) (extension, `[formal-v5]` section) | **T20 — the complete parity classification of the gapped screen**: `gapTwoTube_isInformationSet_iff_parity` — the gap-2 width-2 screen is an information set **iff `n` is odd and `n ≤ 2(t+1)`**. Odd cylinders: *full adjacent capacity at the same sharp threshold* (middle-column reconstruction + two fans zero row 1; the descent to the seed is algebraic — the distance-2 walk is transitive exactly on odd cycles). Even cylinders: never (v4's checkerboard + the degenerate `n = 2` case) | "the general odd-`n` gapped-screen threshold is left open" (v4's honest-scope note; only the `gapTwo_five_two` decided instance) | **machine-checked, sharp, complete** — the last width-2 question closed; tilt is irrelevant, separation matters exactly through cycle parity |
| [`ModularCore.lean`](OPHProofChain/ModularCore.lean) | **T21 — the D3 finite (type-I) modular core**: `kms` (existence — the algebraic KMS identity for `Δ_ρ = ρ·ρ⁻¹` under `ω = tr(ρ·)`), **`kms_unique`** (*any* map satisfying the KMS identity equals `Δ_ρ` — no linearity assumed), automorphism + flow structure, `modular_eq_id_iff_tracial` (every non-tracial state ticks), the faithful-state axioms discharged (`state_one/star/nonneg/faithful`), and the ticking-qubit witness | "the one Layer-2 link with no isolable finite-mathematics core (Tomita–Takesaki/Bisognano–Wichmann)" — fully open tex | **the finite core exists and is machine-checked**; what stays physics is exactly the BW identification (modular flow = boosts) + the scaling limit — D3 is now graded like every other Layer-2 link |
| [`HexacodePort.lean`](OPHProofChain/HexacodePort.lean) (extension, `[formal-v5]` section) | **T22 — the full weight distribution** `A₀ = 1, A₄ = 45, A₆ = 18` (enumerator `x⁶ + 45x²y⁴ + 18y⁶`), kernel-`decide`d | the source file's Python-checked numbers; v4 closed only `d = 4` + self-duality | **every hexacode claim of the `dula/` source file is now closed in Lean** |
| [`ConsensusSafety.lean`](OPHProofChain/ConsensusSafety.lean) | **T23 — the QBFT safety core** (corpus appendix B, attributed): quorum-overlap counting ⇒ no conflicting finalizations (`qbft_safety_core`, composed `qbft_safety` at `n = 3f+1`), the general-`n` sizing, **and the boundary finding `quorum_overlap_gap`**: the appendix's "A6 guaranteed by A3" fails for `n > 3f+1` at fixed quorum `2f+1` | written proof sketch in the appendix, unformalized (outside the chain, inside the corpus) | **machine-checked, with a formal caveat the prose missed** — liveness/optimality stay external citations (DLS88, LSP82), honestly |
| [`LedgerNumerics.lean`](OPHProofChain/LedgerNumerics.lean) | **T24 — run-matrix conversion constants theorem-form**: `C_geom` to 7 digits, `C_geom·A`, the headline `Δν_min ∈ (9.084, 9.085)×10⁻¹⁷` (print 9.1 rounds up — safe), design point (0.550 N, 56.12 gf, SNR 1.10×10⁷), the lock-in floor **exactly** `10⁻⁶/30` (`√(2/1800) = 1/30`), and the battery-coupon ceiling `∈ (1.02, 1.03)×10⁻¹¹` | hand arithmetic in DOCUMENT C; DOCUMENT A printed the coupon ceiling as "≲ 1×10⁻¹¹ (≈ 0.5 gf)" | **machine-checked; one erratum found and fixed** — the coupon ceiling was understated ~3 % in the unsafe direction; DOCUMENT A §1.9 now prints `≲ 1.1×10⁻¹¹ (≈ 0.58 gf)` with an erratum note |

## The v8 campaign, in one table

| Module | Result | Was (proof chain v7) | Is now |
|---|---|---|---|
| [`RouteA.lean`](OPHProofChain/RouteA.lean) (extension, `[formal-v8]`) | **T32 — universal termination**: `misMeasure` (lexicographic stratum-mismatch counts) strictly decreases under every accepted transaction ⟹ `decodeStep_wellFounded` (strong normalization), `no_infinite_decode_run`, `exists_normalForm_extension`, `routeA_universal_settlement` (every schedule terminates AND lands on the tube-pinned record) | "honest leftover: arbitrary-schedule termination (uniqueness already covers every terminating schedule)" | **no scheduler can run forever — the roster names a repair, it is not needed for repair to terminate** |
| [`Rule90Readout.lean`](OPHProofChain/Rule90Readout.lean) (new, native) + [`RouteA.lean`](OPHProofChain/RouteA.lean) corollaries | **T31 — the readout trichotomy** (from `oph_sim/FINDINGS.md` item 10, sharpened): `tubeData_surjective_iff` (`2(t+1) ≤ n` ⟺ every tube reading realizable — kernel count through the first isomorphism theorem, fans supplying the kernel bound), `tubeData_bijective_iff` (`n = 2(t+1)` — the double extreme), `readout_trichotomy`; Route-A landing: `exists_unrealizable_tube_iff` (`n < 2(t+1)` ⟺ empty fibers exist = T27.4's regime), `all_tubes_realizable`, `no_stall_at_threshold` | the bits/unknowns table was a simulation observation; the `n > B` row said only "ghosts exist" | **machine-checked and stronger: above threshold every reading is realizable (ghosts, no empty fibers); at threshold bijective; below, stalls possible — the stall dichotomy has content exactly below the jewel's threshold** |
| [`Rule90Propagation.lean`](OPHProofChain/Rule90Propagation.lean) (new, native) | **T30 — the local-decodability phase boundary** (from `oph_sim/FINDINGS.md` items 1–3): `Inferable` (the three directed readings of the constraint) + `inferable_sound`; `spread_screen_inferable_iff` — screens with pairwise column ring-distance ≥ 3 have propagation closure = themselves (**zero** local inferences, ever); `adjacent_closure_complete` — the tube's closure is the whole block at the threshold; `tube_information_set_via_propagation` — T9 re-derived through the closure; **`violet_exhibit`** — `n=8, g=3, t=3`: information set (T25) with zero locally-derivable bulk cells | the sim's stall scan found 212 determined-but-locally-dark configs, ring-distance ≥ 3 in every one; the two-line argument lived in FINDINGS prose | **determination and local derivability provably split; the sim's flagship violet cell is a theorem** (the gap-2 crawl's completeness is the named leftover) |
| [`ModularFlow.lean`](OPHProofChain/ModularFlow.lean) (extension, `[formal-v8]`) | **T33 — Skolem–Noether, finite dimension**: `algEquiv_matrix_inner` (every `ℂ`-algebra automorphism of `Matrix ι ι ℂ` is inner — classical intertwiner construction, `U·e_j := φ(E_{j i₀})·w`); `kms_algEquiv_structure` (any KMS-satisfying automorphism IS the modular map, inner with conjugator `c·ρ`, `c ≠ 0`) | "extending beyond Hamiltonian-implemented flows needs Skolem–Noether — mathematically standard, not included here" | **the Hamiltonian form is provably generic — there is no non-inner automorphism a rival clock could use**; BW + scaling limit stay physics |
| [`SimplicialSurface.lean`](OPHProofChain/SimplicialSurface.lean) (new, native) | **T35 — a surface for the twelve ports** (holes-audit F24 residue): `TriangulatedSphere` (faces, edges, closedness, Euler = the named topological input); `edges_eq_biUnion` (the edge set is forced); **`three_faces_eq_two_edges` and `degree_sum_eq_two_edges` PROVEN** by double counting (they were `sphere_defect_count`'s assumed equations); `defect_count`/`twelve_ports` consume the v5 theorems unchanged; `ofFn` indexed constructor + kernel-checked `icosahedron` (20/30/12, all degrees 5, `icosahedron_ports`) | `sphere_defect_count` consumed three assumed equations over bare `(V,E,F,deg)`; "any all-triangle closed surface" described absent structure | **the equations are facts of a surface; L0 (that the collar IS such a complex) unchanged as the named physics** |
| [`Rule90Slope.lean`](OPHProofChain/Rule90Slope.lean) (new, native) | **T34-lite — sloped screens pinned down**: `slopeTube` (floor convention — the committed sweep artifacts' definition, now formal), `slopeTube_zero_eq_tubeSet`, `slopeTube_not_informationSet` (the failure half at EVERY slope, free from counting), kernel-checked threshold instances at slopes 1/2, 1/3, 2/3 (`n = 7, 8, 10`) | the slope conjecture lived in prose + evidence artifacts; the Lean tree had no definition to attach it to | **the conjecture is now a precise in-tree statement with its negative half proven and sample positives kernel-checked; the general positive half is THE named open item (sheared-CA sketch recorded in the chain doc) — closed in v9, next table** |

## The v9 campaign, in one table

| Module | Result | Was (proof chain v8) | Is now |
|---|---|---|---|
| [`Rule90Lipschitz.lean`](OPHProofChain/Rule90Lipschitz.lean) (new, native) | **T36 — the Lipschitz worldline theorem**: `pathScreen` (adjacent-pair screen along an integer column path), `pathScreen_fan` (downward two-chain fan induction: at level `k` below the top the closure covers the width-`2k+2` interval; the 1-Lipschitz bound is exactly what keeps each level's screen pair inside the previous interval), `pathScreen_closure_complete` (complete local decodability at `n ≤ 2(t+1)` for EVERY 1-Lipschitz worldline — T30b extended from the static observer to every causal observer), `pathScreen_isInformationSet_iff` (sharp, uniformly in the path), **`slopeTube_isInformationSet_iff` — the slope conjecture (F6), closed** for all `p ≤ q`, sharp; beyond Lipschitz: `pairScreen_class_6_2` (the complete `(6,2)` classification — decodes ⟺ the LAST step is Lipschitz, first step free: order-sensitive), `pairScreen_slope2_8_3`/`pairScreen_teleport_8_3` (at `(8,3)` all `8^4` paths decode — sweep in `evidence/path_screen_sweep.txt`), `pairScreen_slope2_fails_10_4`/`pairScreen_late_jump_fails_10_4`/`pairScreen_early_jump_10_4` (at `(10,4)` the universality dies: superluminal screens fail at exact capacity) | the positive half of the slope conjecture was THE named open mathematics item (v8 recorded a sheared-CA attack sketch); T30b covered only the static adjacent tube; the arbitrary-subset question had no machine-checked walls | **the slope conjecture is a theorem — sharp at every rational slope `≤ 1`, subsumed by the strictly stronger Lipschitz worldline theorem (any speed-`≤ 1` observer, zigzags and negative slopes included, by local propagation alone); the only remaining open mathematics is the arbitrary-subset classification, now provably wild (order-sensitive at `(6,2)`, all-decode at `(8,3)`, capacity-failures at `(10,4)`) plus the gap-2 crawl characterization** |
| [`Rule90Crawl.lean`](OPHProofChain/Rule90Crawl.lean) (new, native) | **T37 — the gap-2 crawl, classified**: `gapTwo_middle_inferable` (the enclosed middle column, one down-rule per cell), `gapTwo_row1` (row 1 fully inferable at `n ≤ 2t+1` — union of two T36 fans with anchors on `[1,t]`; no parity hypothesis), `gapTwo_crawl` (row-0 even offsets, two columns at a time, seeded by the screen's own row-0 cells), **`gapTwoTube_closure_complete_odd`** (odd rings at threshold: closure = the ENTIRE block), `gapTwo_information_set_via_propagation` (T25's odd `g = 2` half re-derived through the closure — the crawl IS a decoder), **`gapTwoTube_closure_incomplete_even`** (even rings: the closure never reaches the seed row), packaged as **`gapTwo_closure_complete_iff_odd`** | the `d = 2` regime was T30's named leftover (`oph_sim/FINDINGS.md` item 1: "the crawl completes on odd rings at threshold" — observed, unproven) | **local decodability of two-column screens is classified at EVERY ring distance** (`d = 1`: complete at threshold, T30b; `d = 2`: complete iff the ring is odd, T37; `d ≥ 3`: nothing infers, ever, T30a); the remaining open mathematics is the arbitrary-subset classification, full stop |

## The v10 campaign, in one table

| Module | Result | Was (proof chain v9) | Is now |
|---|---|---|---|
| [`Rule90Parity.lean`](OPHProofChain/Rule90Parity.lean) (new, native) | **T38 — the parity splitting (oph_sim finding R1, formalized)**: `traj_congr_on_class` (sector blindness: a cell's value depends only on the seed's matching chequerboard class), **`traj_parityProj`** (the sectors never talk), **`isInformationSet_iff_single_parity_ghost`** / **`not_isInformationSet_iff_single_parity_shadow`** (an ARBITRARY cell set on an even ring fails ⟺ a nonzero single-parity ghost is dark — unconditional in `n, t, S`; the containment half of the simulation's shadow-atlas conjecture C1), **`traj_eq_rule60_iterate`** (the bridge: `traj x i j = rule60^[2i] x (j−i)` — Rule 90 IS drifted double Rule 60), **`sectorTrace_succ`**/`sectorTrace_eq_iterate` (R1b: each even-ring sector, in half-ring coordinates, evolves by Rule 60 on `ZMod (n/2)`) | R1 was a numerically-exact simulation finding (23,600 cells, 300 kernel direct sums); C1's containment was a 3-line sketch; the arbitrary-subset item had no even-ring reduction | **the even-ring half of the last open mathematics item factors, by theorem: arbitrary subsets classify sector-by-sector; what remains on even rings is Rule-60 zero-set rigidity on the half ring (probed rigid through `m = 13`; minimal rigid window exactly `⌊m/2⌋`)** |
| [`Rule90TwoPower.lean`](OPHProofChain/Rule90TwoPower.lean) (new, native) | **T39 — two-power universality (oph_sim conjecture C3, closed)**: `rule60_iterate_two_pow_apply` (the doubling lemma — no binomials), `rule60_iterate_self_eq_zero` (Rule 60 is nilpotent on `n = 2^k`), `rule60_apply_eq_of_eq_zero` (the all-ones funnel), **`pairScreen_isInformationSet_two_pow`** / **`pairScreen_isInformationSet_iff_two_pow`** / **`pathScreen_isInformationSet_iff_two_pow`** (EVERY worldline pair screen — teleports included, no causality hypothesis — decodes ⟺ `n ≤ 2(t+1)`), `pairScreen_teleport_4_1` (kernel instance) | C3 was "exhaustive at `n = 8`, 0 failures in 3.2M samples at `n = 16/32/64`" with a u-adic sketch; T36's `(8,3)` all-decode exhibit was unexplained | **on two-power rings the beyond-Lipschitz wildness of T36 vanishes by theorem: the arbitrary-worldline case is CLOSED there, sharp, path-uniform** |
| [`Rule90Diagonal.lean`](OPHProofChain/Rule90Diagonal.lean) (new, native) | **T40/T41 — the lone diagonal observer (new; surfaced by v10 probe F4)**: `diagScreen` (ONE cell per row along a lightlike diagonal), `rule60_prefix_kill` (triangular interval kill), `rule60_iterate_double_reindex` (diagonal readouts = fixed-site Rule-60 iterates), **`diagScreen_isInformationSet_iff_odd`** (odd rings: IS ⟺ `n ≤ t+1` — meets the universal counting bound EXACTLY; the first counting-tight family in the tree), **`diagScreen_not_isInformationSet_even`** (even rings: never, at any horizon), **`diagScreen_pair_isInformationSet_iff_even`** (two opposite-parity diagonals: sharp at `n ≤ 2(t+1)`, at ANY offset — T18a's lightlike tube generalized offset-free), `diagScreen_pair_same_parity_not_isInformationSet`, kernel instances `diag_five_four`/`diagPair_six_two` | no one-cell-per-row family existed (single timelike columns provably never decode, v3); T18a required the two diagonals adjacent | **a new sharp screen family at the absolute counting bound: the lightlike boost flips the one-cell observer from never-decoding to zero-slack optimal; the odd/even dichotomy is exactly T38's sector structure** |

## What did **not** change (deliberately)

- **SEE (Scalar Edge-Center Exhaustion), MAR, the L1–L7 collar clauses, the uniform product-thickening gate** — still named physical hypotheses. Formalizing them as *hypotheses* is the point; discharging them is physics, not Lean. (v4 made the *consequences* of the collar clauses theorem-form; the clauses themselves are untouched.)
- **G9 (record-ΔS → gravity-ΔS numerical bridge)** — still open. v4 built the record-side formal object (`DeltaSBridge.lean`), which sharpens what G9 must supply: the numerical calibration of that generator against gravity-side ΔS. A null still bounds only `χ·ΔS`.
- **L2.11 (force law)** — the *derivation* from the lab anomaly law is now one machine-checked FTC step (`DarkSector.thin_device_force`); the response law itself remains the declared input. `EnergyCage.lean` still prices it.
- **P's source branch** — unchanged: `ProotReported` enters as the executed solver's published numeral; the two-branch structure and χ-consequences are what is machine-checked.
- ~~The three `sorry`s in `observer-patch-holography/LEAN/Primitives.lean` are untouched~~ — **superseded in v4**: this tree now carries an attributed copy of the core with all three discharged (`Core/Primitives.lean`). The OPH team's own repo is still untouched (their call); upstreaming from here is a file move.

## Related audits

`../formal_audits/` contains raw audits of the `dula/` repos (Aristotle-generated Lean corpora). Verdict in short: not proof-chain-relevant (see `PIE_AUDIT_RAW.md`, `DULA_REPOS_AUDIT_RAW.md`, and proof chain v3 §9).

## File-level axiom audit

Every module ends with `#print axioms` on its headline theorems. Full sweep
after the v10 campaign (2026-07-10): **environment-level `collectAxioms` over
all 1284 non-internal theorem/def declarations in BOTH namespaces
(`OPH.*` + `OPHProofChain.*`), across 38 modules** (fresh `lake build`,
8287 jobs, clean — the same stronger-than-self-audit method the adversarial
audit used, and the same count filter as v9: `.thmInfo`/`.defnInfo`
constants, `isInternal` names excluded — earlier campaign counts used a
wider constant filter, so counts across versions are not directly
comparable; the invariant that matters is CLEAN);
all report subsets of `[propext, Classical.choice, Quot.sound]`;
`symmetricPair_not_locallyConfluent`, `symmetricPair_normalForm_iff` (fully
axiom-free), and `quorum_overlap_gap` report strictly fewer than the trio. **No `sorryAx` anywhere in the project —
including `Core/Primitives.lean`, whose three source `sorry`s are
discharged here.** (`lake build` output greps: `sorryAx` count 0; no axiom
line outside the standard trio.)

The only remaining build warnings are cosmetic: four "automatically included
section variable(s) unused" notes in the untouched generic section of the
imported `Core/Primitives.lean`, and a handful of pre-existing v3 linter
notes (`push_neg` deprecation etc.) kept to preserve the v3 files byte-for-byte.

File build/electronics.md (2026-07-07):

# Milestone-1 Electronics

All the electronics subsystems of the self-read PoC, as chapters. Each chapter
opens with its connection diagram — **click a diagram to open the full-size SVG**.

Mechanical jig: `milestone1_jig.scad`. Firmware/logging: `chi_nu_poc.yaml`.
Staged build walkthrough: `MILESTONE_1_build.md`. All parts are from your stock.

**Contents**
1. [Characterize the rings (Stage 0)](#1-characterize-the-rings-stage-0)
2. [System overview](#2-system-overview)
3. [Controller, power & I²C bus](#3-controller-power--ic-bus)
4. [Drive stage](#4-drive-stage)
5. [Peak detector (RX)](#5-peak-detector-rx)
6. [TX select (Stage 1b)](#6-tx-select-stage-1b)

---

## 1. Characterize the rings (Stage 0)

Stage 0 piezo characterisation rig

*Click to open `stage0_characterization.svg` full-size — generated from
`schematic/stage0_characterization.sch` (relative/anchored placement).*

Before any custom electronics, measure the bare rings on the bench. This is
**Stage 0** of the [build walkthrough](MILESTONE_1_build.md) — pure
characterisation with no soldered circuit beyond a single series resistor. It
fixes the two numbers every later chapter leans on: the resonance `f_r` that
sets the drive frequency in [Chapter 4](#4-drive-stage), and the static `C0`
that sizes the hold cap in [Chapter 5](#5-peak-detector-rx). It is genuinely
useful even if you stop here for the day. You need a signal generator and an
oscilloscope — the **Rigol MHO954** is both.

### The rig — one series sense resistor

The ring is electrically a small capacitor `C0 ≈ 2 nF` with sharp *motional*
resonances on top. To see them, drive it through a series **R_sense** and watch
two nodes:

- **CH1** (×10 probe) on the **drive node** — the generator output.
- **CH2** (×10 probe) on the **piezo node** — between R_sense and the ring.

The current into the ring is `(CH1 − CH2)/R_sense`. The ring's **cold** face goes
to GND, common with the generator ground. That is the whole circuit; the three
measurements below all reuse it.

| Ref | Part | Value | Why |
|---|---|---|---|
| R_sense | any ¼ W resistor | **100 Ω** | turns ring current into a CH2 voltage; matches the Stage-0 series R |
| Probes | ×10 (10 MΩ) | — | a ×1 probe's 1 MΩ would load the high-Z ring and flatten Q |
| GND | — | — | ring cold face → common gen/scope ground |

> **⚠ Solder the rings gently.** The electrode is a thin silvered film on the
> ceramic — keep the iron on it **under ~1 s**. Lingering heat blisters and
> de-coats the patch and can locally depole the ceramic. A ring with a small
> de-coated spot is still usable for first tests — bridge it with a thin ring of
> solder to the surrounding intact electrode — but expect a slightly lower Q and
> weaker coupling from it, so don't make it your reference ring.

### Use 1 — find the resonances (`f_s`, `f_p`, `Q`)

Generator = **sine**, sweep **1 kHz → 1 MHz** at ~1–2 Vpp, watch CH2. Each mode
leaves **two marks, record both**:

- **CH2 dip = series resonance `f_s`** — ring impedance minimum → current
  maximum. This is the frequency at which a low-impedance source (the ~100 Ω
  rig, or the Stage-1 buffer + CD4066) pumps the **most energy into the ring**.
- **CH2 peak = parallel resonance `f_p`, slightly above `f_s`** — impedance
  maximum. An open-circuit *receiver* responds strongest near here. The spacing
  gives the electromechanical coupling: `k_eff² ≈ (f_p² − f_s²)/f_p²`.

The **phase flips** near both. Expect a **radial mode ~20–70 kHz** and a
**thickness mode at a few hundred kHz**. If the scope has a **Bode / FRA**
(frequency-response) function, use it — it auto-sweeps gain + phase and shows
the dip/peak pair directly. Read `Q = f_r / Δf` from the −3 dB width of either
mark.

> **⚠ Which frequency to drive at (Run-1 erratum).** Run 1 logged only the CH2
> *peak* (43.5 kHz) — that is `f_p`, not `f_s`. With Q ≈ 75 the bandwidth is
> only ~0.6 kHz, and TX energy transfer through a ~100 Ω source peaks near
> `f_s`, which sits a few % *below* `f_p` for these rings. Before freezing the
> Stage-1 `drive_freq`, sweep the burst frequency between `f_s` and `f_p` and
> keep whatever **maximizes the coupled RX amplitude** (expect it near `f_s`;
> the C_ij values may come out several × larger than the Run-1 numbers).

### Use 2 — ringdown (`Q`, and the same-port self-read)

Same rig, generator = **burst** (20–100 cycles at `f_s`, low repeat rate). Watch
CH2 *after* the drive stops: a **decaying sinusoid** — that decay **is** the
self-read signal. `Q = π·f_r·τ`, where `τ` is the 1/e envelope time; cross-check
it against the sweep value. Note: an idle generator usually holds **50 Ω** to
ground, which damps the ring and *understates* Q — set the output to **High-Z**
for a truer number.

### Use 3 — cross-coupling matrix `C_ij`

Mount the rings in the jig on the **shared carrier plate** — the plate is the
coupling medium, and there is **no wire** between rings. Drive ring 0 through
R_sense; read **ring 1's** hot node on CH2/CH3 (its cold face → common GND).
Record **amplitude and phase** at the drive frequency for each ordered pair →
the 3×3 matrix by hand. In the `row` jig layout, expect a distance gradient
(**C01 > C02**).

### Stage-0 output (what to record)

Per ring: **`f_s` and `f_p` for the radial mode** (dip *and* peak — see the
erratum above), `f_thickness`, `Q`, ringdown `τ`, static `C0` (DMM capacitance
mode, well below resonance — expect ~1.5–3 nF; Run 1 measured 2.26 nF), plus the
**3×3 cross-coupling matrix**. That fixes the Stage-1 drive frequency and
confirms the rings are usable before you build a single buffer. No voltage here
exceeds a few volts — ordinary bench safety.

---

## 2. System overview

System overview block diagram

*Click to open `system_overview.svg` full-size — generated from
`schematic/system_overview.sch` (relative/anchored block placement).*

<details><summary>Inline Mermaid version (legacy — kept for now)</summary>

> Text-based topology, renders natively on GitHub. Superseded by the generated SVG
> above (maintainable source: `schematic/system_overview.sch`); kept for a few
> iterations, slated for removal.

```mermaid
flowchart LR
  PWR["Power<br/>one 3.3 V rail (USB / 1S LiPo)"]
  subgraph PoC["self-contained PoC (no force-bearing cable)"]
    direction LR
    XIAO["Xiao ESP32-C6<br/>(ESPHome)"]
    BUF["Drive buffer<br/>S8050 / S8550"]
    TX["Ring 0 (TX)"]
    RX["Rings 1-2 (RX)<br/>+ Ring 0 self"]
    AMP["Amps x120 x3<br/>MCP6022 2-stage"]
    PK["Peak detectors x3<br/>1N5819 / C_hold / R_bleed"]
    ADS["ADS1015<br/>(I2C ADC, mux + PGA)"]
  end
  HA["Home Assistant<br/>(timestamped log = evidence bundle)"]

  PWR -->|"3.3 V"| XIAO
  PWR -->|"3.3 V"| BUF
  XIAO -->|"DRIVE GPIO2 (LEDC 50%)"| BUF
  BUF -->|"~1.9 Vpp burst"| TX
  TX -->|"plate coupling"| RX
  RX -->|"ringdown (mV)"| AMP
  AMP -->|"x120"| PK
  PK -->|"held DC peak"| ADS
  ADS -->|"I2C SDA22/SCL23"| XIAO
  XIAO -->|"RESET GPIO21"| PK
  XIAO -->|"WiFi"| HA
```

</details>

How the subsystems connect into one bounded, self-reading object.

### Signal / data flow

The loop **drive → self-read → record → (predict)** lives entirely on the object:
the Xiao drives a ring, the rings couple through the shared plate, the detectors
hold each response, the ADS digitizes, and HA records it with timestamps. That
recorded, reproducible coupling matrix is the Milestone-1 self-read receipt.

### Where things live

| Block | Location | Key parts |
|---|---|---|
| Carrier + ring jig | `milestone1_jig.scad` | 3D print, 3 piezo rings |
| Drive stage | Chapter 4 | S8050/S8550, R_base 1k, R_drive 100Ω (your stock) |
| TX select (full 3×3, Stage 1b) | Chapter 6 | CD4066 quad bilateral switch, VDD = 3.3 V |
| Ring → **×120 amp** → peak detector ×3 | Chapter 5 | **MCP6022/TLV2372 ×3 (order)**, 1N5819, 10 nF, 10 MΩ, reset NPN |
| ADC | Chapter 3 | GY-ADS1015 (I²C, mux, PGA) |
| Controller / power / bus | Chapter 3 | Xiao ESP32-C6; USB-C (bench) / 1S LiPo on BAT pads (untethered) |
| Firmware / logging | `chi_nu_poc.yaml` | ESPHome → Home Assistant |
| Whole build, staged | `MILESTONE_1_build.md` | — |

### Pin map (summary)

> **⚠ Corrected 2026-07-05 — this is the real XIAO ESP32-C6 pinout.** The C6
> module exposes only GPIO 0, 1, 2, 21, 22, 23, 16, 17, 18, 19, 20. The earlier
> map (GPIO3/4/5 select, GPIO6/7 I²C) was the XIAO ESP32-**C3** pinout; on the
> C6 those pins are not on the headers at all (GPIO3 powers the RF switch).

| Xiao pin | Net | Block |
|---|---|---|
| GPIO2 (D2) | DRIVE (LEDC, 50 % duty) | drive stage |
| GPIO21 (D3) | RESET | peak detectors |
| GPIO22 / GPIO23 (D4/D5) | SDA / SCL | ADS1015 |
| GPIO0 / GPIO1 / GPIO18 (D0/D1/D10) | TX0/TX1/TX2 select | full-matrix TX select (Stage 1b) |
| 3V3 / GND | the one rail | all |

### What completes Milestone 1 (receipt)

1. **Coupling matrix** logged in HA — at Stage 1a, column 0 (C00, C01, C02);
   reproducible across repeats (R_U).
2. **Same-port readback** — C00 with the reset-after-drive sequence.
3. **Clear separation** of the active matrix from **both controls**: the
   shuffled (no-drive) control *and* the off-resonance control — the latter
   carries the same electrical feedthrough but no mechanical resonance, so it
   is what proves the matrix is *coupling*, not crosstalk.

No weighing, no lift claim — this proves the self-reading object exists. The
record-level ΔS it later yields is what lets us check the ΔS-estimator bridge
empirically (see `ANS:/reply_to_bmu.md`).

### Build order (fastest path, parts on hand)

1. Print the jig (`milestone1_jig.scad`); solder ring leads.
2. Stage 0 on the Rigol → f_s + f_p, ringdown, cross-coupling (no electronics).
3. Power + Xiao + I²C + ADS (Chapter 3); confirm 0x48 in the boot log.
4. One drive buffer (Chapter 4) + three amp+detector channels (Chapter 5).
5. Flash `chi_nu_poc.yaml`; **Sweep**, then **Sweep (shuffled control)** and
   **Sweep (off-resonance control)**; confirm the matrix stands above both
   controls → receipt.

### Full instrument

Full instrument

---

## 3. Controller, power & I²C bus

Controller, power and I2C connection diagram

*Click to open `controller_power.svg` full-size — generated from
`schematic/controller_power.sch` (relative/anchored placement).*

<details><summary>Inline Mermaid version (legacy — kept for now)</summary>

> Power tree + I²C bus, text-based. Superseded by the generated SVG above
> (maintainable source: `schematic/controller_power.sch`); kept for a few
> iterations, slated for removal.

```mermaid
flowchart LR
  USB["USB-C (bench)"]
  LIPO["1S LiPo 3.7 V<br/>on XIAO BAT pads (untethered)"]
  REG["Xiao onboard<br/>charger + regulator"]
  V33["+3.3 V rail (the only rail)"]
  XIAO["Xiao ESP32-C6"]
  ADS["ADS1015 @0x48 (ADDR to GND)"]
  AMP["Amps x120 + detectors"]
  SW["CD4066 TX select"]
  BUFR["Drive buffer"]

  USB --> REG
  LIPO --> REG
  REG --> V33
  V33 --> XIAO
  V33 --> ADS
  V33 --> AMP
  V33 --> SW
  V33 --> BUFR
  XIAO <-->|"I2C 400 kHz · SDA22/SCL23 · 4.7k pull-ups"| ADS
```

</details>

The Xiao ESP32-C6, its supply, the I²C link to the ADS1015, decoupling, and
grounding.

### Power: one 3.3 V rail, two sources

> **Rev 2 (2026-07-05) — the 2S + 7805 plan is gone, deliberately.** Three
> reasons: **(1)** a 7805 needs ≥ ~7 V in (2 V dropout); a "7.4 V" 2S LiPo
> spends most of its discharge curve at 6.6–7.4 V, so the 5 V rail would sag
> out of regulation. **(2)** an AMS1117-3.3 fed from 7.4 V dissipates
> (7.4−3.3 V)·0.35 A ≈ 1.4 W at WiFi peaks — far past a SOT-223 without a
> plane. **(3)** the 5 V rail bought nothing: the push-pull output swing is
> capped at 0.7–2.6 V by its 0–3.3 V *base* drive, not by the rail (Chapter 4).
> Everything now runs from one 3.3 V rail, which the Xiao itself provides.

**Bench (Milestone 1 — cables are fine here):**
- USB-C into the Xiao → its onboard regulator gives **3.3 V** to the ESP,
  ADS1015, the six amp op-amps, the CD4066, and the drive buffer.

**Untethered (later, for the balance run — no cables):**
- A **1S LiPo (3.7 V) soldered to the XIAO BAT pads** on the module's underside.
  The Xiao's onboard charger manages it (charges over USB-C), and the same
  3.3 V rail comes out — zero extra parts.

| Rail | Source (bench) | Source (untethered) | Feeds |
|---|---|---|---|
| +3.3 V | Xiao onboard regulator (USB) | 1S LiPo on BAT pads | everything |
| +5 V (optional) | USB 5 V pad / bench supply | — (not needed) | only the LM358-fallback amps or an LM386 drive experiment |
| GND | common star | common star | everything |

### Pin map (Xiao ESP32-C6 — real header pins)

| Pin | Net | Goes to |
|---|---|---|
| GPIO2 (D2) | DRIVE (LEDC, 50 % duty) | drive buffer base (R_base) — Chapter 4 |
| GPIO0 / GPIO1 / GPIO18 (D0/D1/D10) | TX0/TX1/TX2 | CD4066 controls — Chapter 6 (Stage 1b) |
| GPIO21 (D3) | RESET | all peak-detector reset bases (10 kΩ each) — Chapter 5 |
| GPIO22 (D4) | SDA | ADS1015 SDA |
| GPIO23 (D5) | SCL | ADS1015 SCL |
| 3V3 | +3.3 V | ADS VDD, amps, CD4066 VDD, drive buffer |
| BAT pads (underside) | battery | 1S LiPo (untethered mode) |
| GND | GND | common star |

> These match `chi_nu_poc.yaml` (rev 2). For Stage 1a (fixed TX) only GPIO2,
> GPIO21, GPIO22, GPIO23 are needed; GPIO0/1/18 stay free until the full-matrix
> select. Free for later sensors: GPIO16/17 (UART), GPIO19/20.
> **Do not copy a XIAO ESP32-C3 pin map onto this board** — GPIO3/4/5/6/7 are
> not on the C6 headers (GPIO3 powers the C6's RF switch).

### I²C bus

- ADS1015 address **0x48** → tie its **ADDR pin to GND**.
- **SDA = GPIO22, SCL = GPIO23** (the C6's default I²C pins, D4/D5), 400 kHz.
- **Pull-ups: 4.7 kΩ on SDA→3.3 V and SCL→3.3 V.** The GY-ADS1015 module usually
  has these onboard — check; add external 4.7 kΩ only if the bus doesn't ACK.
- Keep I²C wires short; route them away from the drive/ring leads.

### Decoupling & grounding

- **100 nF** ceramic right at each IC's VDD–GND (Xiao 3V3, ADS1015 VDD, drive
  buffers +5 V). Use them generously.
- **10 µF** bulk on each rail (+5 V and +3.3 V) near where it enters the board.
- **Single star ground.** Tie ADS GND, ESP GND, detector grounds, drive-buffer
  GND, and battery/USB GND to one point. Keep the drive stage's current-pulse
  return off the long thin traces shared with the detector grounds.
- The ESP is WiFi — keep the antenna end clear of the ring/detector analog area, and
  lean on the lock-in/ABBA + shuffle control to reject any pickup.

### Build order

1. Lay the GND star and the +3.3 V / +5 V rails first; add bulk 10 µF + 100 nF.
2. Power the Xiao (USB), confirm 3.3 V and 5 V pads with the DMM.
3. Wire I²C to the ADS1015; confirm the ESP sees it at 0x48 (ESPHome boot log).
4. Add the reset line (GPIO21) and the detector reset bases.
5. Then the drive stage (Chapter 4) and detectors (Chapter 5).

---

## 4. Drive stage

Drive stage connection diagram

*Click to open `drive_stage.svg` full-size — generated from
`schematic/drive_stage.sch` (relative/anchored placement).*

<details><summary>Inline Mermaid version (legacy — kept for now)</summary>

> Push-pull buffer topology (RKM values, e.g. `100R` = 100 Ω), text-based.
> Superseded by the generated SVG above (maintainable source:
> `schematic/drive_stage.sch`); kept for a few iterations, slated for removal.

```mermaid
flowchart LR
  LEDC["ESP LEDC GPIO2<br/>(f_r square wave)"]
  RB["R_base 1k"]
  B(("B<br/>base node"))
  Q1["Q1 S8050 NPN"]
  Q2["Q2 S8550 PNP"]
  OUT(("OUT<br/>emitters tied"))
  RD["R_drive 100R"]
  RING["Piezo ring<br/>(TX, ring 0)"]
  V33["+3.3 V rail"]
  GND["GND"]

  LEDC --> RB --> B
  B --> Q1
  B --> Q2
  V33 -->|"collector"| Q1
  Q1 -->|"source on rising"| OUT
  Q2 -->|"sink on falling"| OUT
  Q2 -->|"collector"| GND
  OUT --> RD --> RING
  RING -->|"cold terminal"| GND
```

</details>

Turns the ESP32 LEDC square wave (0–3.3 V logic) into enough current/voltage to
ring a piezo (~2 nF capacitive load) at its resonance. One buffer per TX ring.

### Topology: complementary emitter-follower (push-pull)

LEDC → R_base → shared base node → **S8050 (NPN, top)** + **S8550 (PNP, bottom)**
emitter-follower pair → OUT → R_drive → ring. The pair sources current to charge
the piezo cap and sinks it to discharge — exactly what a capacitive load needs.

| Ref | Part (your stock) | Value | Why |
|---|---|---|---|
| Q1 | S8050 NPN (J3Y) | — | sources current on the rising half |
| Q2 | S8550 PNP (2TY) | — | sinks current on the falling half |
| R_base | 1206 | **1 kΩ** | LEDC → both bases; limits base current |
| R_drive | 1206 | **100 Ω** | series to the ring: damps transients, limits peak current |
| Supply | 3.3 V rail | **+3.3 V** | follower rail; GND for the PNP collector — see swing note below |
| (opt.) D_ab ×2 | 1N4148 | — | class-AB bias between bases to soften crossover (optional) |

### What amplitude to expect

An emitter-follower loses ~0.6–0.7 V per Vbe, so a 0–3.3 V base drive gives an
output swing of roughly **0.7 V → 2.6 V (≈ 1.9 Vpp)**, with a crossover deadband
in the middle. **The swing is set by the base drive, not the rail** — a 5 V rail
gives exactly the same 0.7–2.6 V, which is why rev 2 runs the buffer from the
3.3 V rail (the NPN sits at V_CE ≈ 0.7 V at the top of the swing — still active,
not saturated). ~1.9 Vpp is plenty to *ring* a high-Q resonator at its f_r
(energy builds over ~Q cycles), and the ×120 RX amps (Chapter 5) handle the
small coupled signals. If you ever need more drive:

- **Lift the base swing** (level shifter or gate driver into a higher rail) —
  raising the rail alone does nothing, or
- **Use the LM386** (you have it) as the drive amp for the **radial mode** (tens
  of kHz): AC-couple LEDC in, set gain (20–200), big swing out. Note it needs a
  **≥ 4 V supply** — that is what the *optional* 5 V bench rail is for. Its
  ~300 kHz BW won't serve a ~400 kHz thickness mode — use the push-pull there.

Current is modest: `I_pk ≈ 2π·f·C0·V` ≈ 0.6 mA at 50 kHz sine, ~19 mA transient
on the square edges through R_drive (C0 ≈ 2.3 nF). R_drive = 100 Ω is
comfortable; decouple the rail with 10 µF + 100 nF at the transistors.

### TX selection — which ring is driven

Each ring is permanently wired to its own RX peak detector (Chapter 5). Driving one
ring at a time while the others stay clean RX inputs is the only fiddly part — so
stage it:

**Stage 1a (now): fixed TX.** One buffer drives **ring 0** only. Rings 1 & 2 are
RX-only; ring 0 also has a detector (self-read C00). You measure column 0 of the
matrix (C00, C01, C02) + the shuffle control. **That is already a valid Milestone-1
receipt** — reproducible coupling, a distance gradient, same-port readback, and a
control — with zero select hardware. Build this first.

**Stage 1b (full 3×3, later): add drive-side selection** — drawn in
[Chapter 6](#6-tx-select-stage-1b). Each idle buffer would otherwise hold its ring
near 0.7 V at low impedance and spoil that ring's RX read, so you need *true high-Z*
on the unselected rings. Cleanest options:

- **A CD4066 analog switch** routes the one buffer's output to the selected ring
  only; unselected rings see an open switch (high-Z). Driven by GPIO0/GPIO1/GPIO18,
  one enable per ring — this matches `chi_nu_poc.yaml`'s three independent TX
  enables, and is the circuit in Chapter 6. (Recommended.) A CD4051 8:1 mux also
  works but expects a binary address, not three enables, so it would need a
  firmware change.
- **Three buffers, firmware-tristated:** each ring its own buffer fed by its own
  LEDC pin; set the *unselected* drive GPIOs to **input/high-Z** (not LOW) so those
  buffers float off. Works, but a floating base picks up noise — less clean.

### Build steps (one buffer)

1. +3.3 V and GND rails on the protoboard (from the Xiao 3V3 pin — Chapter 3).
2. LEDC GPIO2 → **R_base 1 kΩ** → base node B.
3. B → **Q1 (S8050)** base and **Q2 (S8550)** base (bases tied).
4. Q1 collector → **+3.3 V**; Q2 collector → **GND**.
5. Q1 emitter + Q2 emitter → **OUT** (tied).
6. OUT → **R_drive 100 Ω** → ring 0 hot terminal (TX ring); ring cold → GND.
7. (Optional) two 1N4148 in series between the bases, biased from +3.3 V via a
   resistor, for class-AB — only if crossover distortion bothers you.

Decoupling: 100 nF + 10 µF across +3.3 V near the transistors.

### Sanity check

On the Rigol, scope OUT: a ~1.9 Vpp abrupt waveform at f_r during the burst (the
piezo edge looks rounded — that's the cap charging through R_drive). The RX rings
then show mV-level ringdown that scales with this drive amplitude — the ×120
amps of Chapter 5 exist precisely because it is mV-level.

---

## 5. Peak detector (RX)

RX peak detector connection diagram

*Click to open `peak_detector.svg` full-size — generated from
`schematic/peak_detector.sch` (relative/anchored placement).*

> **History.** Two earlier depictions of this channel —
> [`peak_detector_legacy.svg`](peak_detector_legacy.svg) (hand-drawn) and an
> inline Mermaid sketch — showed the **rev-1 amp-less detector** (ring → 1N5819
> → 1 nF hold). That circuit could not have read the measured 2–10 mV
> off-diagonals (see the rev-2 note below) and is kept only as history.

One per RX ring (×3). It turns the fast piezo ringdown (tens–hundreds of kHz,
decaying in ~ms) into a **held DC peak** the ADS1015 can read at its leisure. That
held value is one entry of the coupling matrix C_ij. The detector measures
*relative* amplitudes, so values are chosen for a clean, repeatable read — absolute
calibration is not needed for Milestone 1.

> **⚠ Rev 2 (2026-07-05) — why there is now an amplifier.** Stage 0 *measured*
> the coupled ring-to-ring signals: **10 mV (adjacent), 5 mV, 2 mV (weak/far
> cells)** at full drive. A 1N5819's forward knee is ~0.15–0.3 V; below that a
> bare diode detector is a square-law device whose output for a 2–10 mV input
> is fractions of a millivolt — at or under the ADS1015's LSB even at maximum
> PGA. **The rev-1 detector could not have read the off-diagonal matrix at
> all.** (The diagonal C_ii was never in danger — the driven ring rings down
> from ~1.5 V.) Fix: amplify each RX channel ~**×120** *before* the diode, with
> a two-stage single-supply op-amp front end. 2 mV → ~0.24 V at the detector;
> 10 mV → ~1.2 V. The 0.2–0.3 V diode drop is then a fixed, repeatable offset
> instead of a wall.

### Step 0 — measure your ring first (2 numbers set everything)

1. **Static capacitance C0** — multimeter cap mode (or the Rigol) across one ring,
   well below resonance. Expect **~1.5–3 nF** for a 38 mm / 5 mm PZT ring. (Design
   assumes C0 ≈ 2 nF; adjust C_hold if very different — see Tuning.)
2. **Resonance f_r and ringdown** — from Stage-0 on the Rigol. Expect a radial mode
   ~**40–70 kHz** and a thickness mode a few hundred kHz. Note the RX peak amplitude.

The ring is electrically a small capacitor C0 with a sharp motional resonance; its
**source impedance** near resonance is roughly `Z ≈ 1/(2π·f_r·C0)`:

| f_r | Z (C0 = 2 nF) |
|---|---|
| 50 kHz | ~1.6 kΩ |
| 100 kHz | ~0.8 kΩ |
| 400 kHz | ~0.2 kΩ |

This low source impedance lets the detector charge a small hold cap fast.

### The chain (per RX channel)

```
ring hot H ─ R_ref 1M ─ GND
      H ─ C_in 10n ─→ A1 (×21) ─→ A2 (×5.7) ─ R_s 100Ω ─ C_c 100n ─┬─ D 1N5819 ─→ N
                     (non-inv., biased V_BIAS)          R_dc 100k ─┤              │
                                                              GND ─┘   C_hold 10n ┼ R_bleed 10M ┼ (R_dis 100Ω + Q_reset) → GND
                                                                       N → ADS1015 AINx
```

| Ref | Part | Value | Why |
|---|---|---|---|
| R_ref | 1206 (stock) | **1 MΩ** | DC-references the ring's hot node |
| C_in | 1206 (stock) | **10 nF** | AC-couples ring → amp (16 Hz HPF vs 1 MΩ bias) |
| A1, A2 | **MCP6022 / TLV2372** (order; one dual per channel) | ×21, ×5.7 | GBW ≥ 3 MHz rail-to-rail; gains 1+100k/5.1k and 1+47k/10k → **~×120** |
| R_bias | 1206 | **1 MΩ** | biases A1.in+ from the shared V_BIAS node |
| V_BIAS divider | 2× 100 kΩ + 100 nF | 1.65 V | **one divider serves all three channels** |
| R_g1/C_g1, R_g2/C_g2 | 5.1k + 1 µF, 10k + 1 µF | — | AC gain only (DC gain 1 → output idles at V_BIAS) |
| R_f1, R_f2 | 100 kΩ, 47 kΩ | — | feedback |
| R_s | 1206 | **100 Ω** | isolates the op-amp from the diode/cap load |
| C_c | 1206 | **100 nF** | AC-couples amp → detector (ground-referenced) |
| R_dc | 1206 | **100 kΩ** | DC return at the diode anode |
| D | **1N5819** (SS14, stock) | — | low drop + fast; *not* 1N4007 |
| C_hold | 1206 (stock) | **10 nF** | hold τ with R_bleed = **100 ms** → <6 % droop over the 3 sequential reads |
| R_bleed | 1206 (stock) | **10 MΩ** | hold decay |
| Q_reset + R_base + R_dis | S8050 + 10 kΩ + 100 Ω (stock) | — | GPIO21 shorts C_hold (τ ≈ 1 µs) between captures |

Time constants: amp output charges C_hold through R_s + D within a couple of
cycles; hold `τ = 10 MΩ · 10 nF = 100 ms`; reset discharge `τ = 100 Ω · 10 nF =
1 µs` (the firmware's 100 µs pulse is generous).

> **LM358 fallback (stock, works today, less clean):** same topology, but its
> 1 MHz GBW means the nominal ×21 stage really delivers ~×11 at 43.5 kHz — total
> ~×55, temperature-dependent at the %-level — and on 3.3 V its output ceiling
> is ~1.9 V, so set V_BIAS ≈ 0.9 V (R_b2 = 39 kΩ) or run the amps from the
> optional 5 V bench rail. Fine for first light; swap to MCP6022 for the
> archived receipt. **Not** the UA741 (needs ± supplies, too slow).

### Bill of materials (all 3 RX channels)

| Qty | Part | Source |
|---|---|---|
| 3 | MCP6022 or TLV2372 (dual RRIO op-amp) | **order** (LM358 = stock fallback) |
| 3 | 1N5819 Schottky | stock (SS14) |
| 3+1 | 10 nF (C_in ×3, C_hold ×3) — 6 total | stock 1206 |
| 3 | 100 nF (C_c) + 1 for V_BIAS | stock 1206 |
| 6 | 1 µF (C_g1, C_g2) | stock 1206 |
| 3 | 10 MΩ (R_bleed) · 3× 1 MΩ (R_ref) · 3× 1 MΩ (R_bias) | stock 1206 |
| 3 ea | 100 kΩ (R_f1), 47 kΩ (R_f2), 100 kΩ (R_dc), 5.1 kΩ (R_g1), 10 kΩ (R_g2) | stock 1206 |
| 3 ea | 100 Ω (R_s), 100 Ω (R_dis), 10 kΩ (R_base) | stock 1206 |
| 3 | NPN (Q_reset) S8050/2N3904 | stock |
| 2 | 100 kΩ (V_BIAS divider) + 100 nF | stock |

> The three Q_reset bases share one GPIO (reset all detectors together) via
> three 10 kΩ resistors — matching the single `pk_reset` line in
> `chi_nu_poc.yaml`. The V_BIAS divider is also shared.

### Build steps (one channel, then ×3)

1. **GND rail**; tie ADS GND, ESP GND, all "→ GND" legs to it (short, star-ish).
2. Build the shared **V_BIAS divider** (100k/100k from 3.3 V, 100 nF to GND).
3. RX ring **cold** → GND. RX ring **hot** → node H; **R_ref (1 MΩ) → GND** at H.
4. H → **C_in 10 nF** → A1.in+; **R_bias 1 MΩ** from V_BIAS to A1.in+.
5. A1: R_f1 100k out→in−; R_g1 5.1k + C_g1 1 µF from in− to GND. Supply 3.3 V,
   100 nF at the pins. A1.out → A2.in+ (DC-coupled).
6. A2: R_f2 47k out→in−; R_g2 10k + C_g2 1 µF from in− to GND.
7. A2.out → **R_s 100 Ω** → **C_c 100 nF** → diode anode node; **R_dc 100 kΩ**
   from that node to GND; **D (1N5819)** cathode → node N.
8. At N: **C_hold (10 nF) → GND**, **R_bleed (10 MΩ) → GND**, **R_dis (100 Ω) →
   Q_reset collector**; Q_reset emitter → GND; base → **R_base (10 kΩ)** → GPIO21.
9. N → **ADS1015 AINx**. Repeat into AIN1, AIN2.

### Capture timing — reset AFTER the burst (both matrix types)

Rev 2 firmware captures **everything after drive-off**: burst → drive off → all
TX switches opened → **~120 µs later a 100 µs `pk_reset` pulse** dumps whatever
the burst coupled in electrically → C_hold then recharges from **pure
mechanical ringdown** → settle → read. Electrical feedthrough therefore never
enters C_ij — and the **off-resonance control** (same burst amplitude at
~29 kHz) verifies that, because it carries the same feedthrough but no
resonance.

**The diagonal C_ii** needs one extra step: during its own burst the driven
ring's amp is saturated (1.5 V × 120 ≫ rail), so the same-port read happens on
a **second burst** whose reset fires `diag_tail_ms ≈ 3 ms` after drive-off —
by then the ringdown (τ = Q/πf ≈ 0.55 ms) is back inside the amp's range and
the held tail is a clean, state-dependent self-read number. Tune 2–5 ms per
ring; C_ii volts are a *separate scale* from off-diagonal volts (tail vs peak) —
compare C_ii only with C_ii across repeats and controls.

### Tuning guide

| Symptom | Fix |
|---|---|
| Off-diagonals too small / noisy | raise ADS PGA (gain 0.512/0.256); check V_BIAS; check C_in orientation/route |
| ADS clips (full-scale) | drop PGA to 2.048; or reduce R_f2 (47k → 22k, gain ×2.9) |
| Amp output clips on the strongest cell | reduce R_f2 as above — keep all three channels at the SAME gain |
| Reading droops before read | shouldn't with τ = 100 ms — check R_bleed value and ADS single-shot mode |
| Diagonal reads ~rail | increase `diag_reset` tail delay (amp still saturated) |
| Diagonal reads ~0 | decrease the tail delay (ringdown already gone) |
| Everything reads ~0 in ACTIVE | drive frequency off resonance — redo the f_s/f_p sweep (Ch. 1 erratum) |
| Weak cells wander over an hour, strong cells don't | that's the diode-knee tempco, not a build fault — interleave controls + log temperature (noise budget below) |

### What "good" looks like

- Amp output on the scope: a clean ×~120 copy of the ringdown, idling at V_BIAS.
- Detector DC output **tracks** the RX ringdown amplitude on the scope.
- Off-diagonals show the expected **distance gradient** in the row layout (C01 > C02).
- The **shuffled control** reads near baseline, the **off-resonance control**
  reads near baseline *despite full drive amplitude*, both clearly below the
  active matrix. That separation is the Milestone-1 receipt
  (quantitative pass thresholds: `MILESTONE_1_build.md` §1.1).
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

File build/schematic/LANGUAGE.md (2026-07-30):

# The `.sch` path language (v2)

One statement per line, `#` starts a comment (except inside quotes), blank
lines ignored. A line ending in `->` or `<-` continues on the next line.

The core idea: **the route is the statement.** You draw wires as paths, and
parts sit inline *on* the paths. Everything can be pinned down manually
(`at`, `up 40`, waypoints) — but nothing has to be: with no hints, placement
advances along the path and the router finds a clear Manhattan route
automatically. Junction dots and connectivity checking are automatic; an
unknown ref or pin fails the build.

```
sheet "Drive stage — push-pull buffer"      # no size: auto-sizes around content
net +5V #e8412f
net GND #2166ac

port LEDC "LEDC GPIO2"                      # no `at`: placed by its first use

LEDC.p -> [res Rb "R_base" 1k] -> BASE      # parts live ON the route
BASE -> up 72 -> [npn Q1 "S8050"].B         # hint steers route & placement…
BASE -> [pnp Q2 "S8550"].B at Rb.b +64,72   # …or pin the part manually…
Q1.C -> +5V                                 # …or no hints at all: autoroute
Q2.C -> GND
Q1.E -> OUT <- Q2.E                         # two paths meet: node OUT + dot
OUT -> [res Rd "100 Ω"] -> [piezo RING "Ring 0"] -> GND
```
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

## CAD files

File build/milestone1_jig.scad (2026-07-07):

// ============================================================
// Milestone-1 piezo self-read jig  (parametric, OpenSCAD)
// Holds the piezo rings at fixed, repeatable spacing on a shared
// carrier plate (the plate is the mechanical coupling medium),
// plus a shelf for the Xiao + protoboard.
//
// Your rings: OD 38 mm, ID 14.8 mm, thickness 5 mm, qty 3.
// Print: PETG or PLA, NO steel inserts (stay nonmagnetic).
//        0.2 mm layers, 30-40% infill, no supports needed.
// Export: set show_rings = false, then render (F6) + export STL.
// ============================================================

// ---------- ring geometry (your parts) ----------
ring_od = 38;        // outer diameter [mm]
ring_id = 14.8;      // inner hole [mm]
ring_h  = 5;         // thickness [mm]
n_rings = 3;

// ---------- fit ----------
pocket_clear = 0.4;  // diametral clearance, ring drops into pocket
peg_clear    = 0.4;  // diametral clearance, center peg vs ring ID
pocket_depth = 1.5;  // locating-rim depth (ring sits mostly proud)
use_center_peg = true;
peg_extra    = 3;    // peg height ABOVE the plate top [mm] (< ring_h)

// ---------- layout ----------
// "row"      -> clean coupling-matrix geometry: a near/far distance gradient
//               (expect C01 > C02). Easiest to validate. START HERE for M1.
// "triangle" -> symmetric coupling (C01 ~ C02 ~ C12) AND the minimal in-plane
//               pattern for later pitch/roll control (3 points span a plane).
// NOTE: in the chi_nu model the lift force is VERTICAL only. In-plane layout
//       gives differential-vertical -> tilt/torque, never lateral thrust. The
//       lift CONTRAST itself is top/bottom -> a separate vertical-stack variant.
layout   = "row";    // "row" or "triangle"
ring_gap = 6;        // edge-to-edge gap between adjacent pockets [mm]

// ---------- carrier plate (coupling medium) ----------
plate_th     = 3;    // thickness; stiffer plate -> different coupling
plate_margin = 10;   // border around the pockets [mm]

// ---------- wire routing ----------
notch_w     = 3;     // channel width for ring leads (fits both face wires) [mm]
notch_dir   = "back";// "back" = toward the electronics shelf (short runs), or "front"
notch_under = 5;     // how far the channel reaches UNDER the ring [mm] (solder relief)
//                      the channel is cut THROUGH the plate, so the underside
//                      solder joint + wire are never squeezed against the print

// ---------- electronics shelf ----------
shelf      = true;
shelf_w    = 45;     // Xiao + small protoboard footprint [mm]
shelf_d    = 35;
shelf_gap  = 8;      // neck gap between active plate and shelf [mm]
shelf_hole_d = 2.6;  // mounting holes (self-tap / M2.5)

// ---------- preview ----------
show_rings = false;   // translucent ghost rings for a fit check (turn OFF to export)

$fn = 96;

// ---------- derived ----------
pocket_d = ring_od + pocket_clear;
pitch    = pocket_d + ring_gap;

function row_positions(n, p) = [ for (i = [0:n-1]) [ (i - (n-1)/2) * p, 0 ] ];
// equilateral triangle sized from the SAME center-to-center pitch as the row,
// so ring_gap means the same thing in both layouts (circumradius = pitch/sqrt3)
function tri_positions(p)    = [ for (a = [90, 210, 330]) [ (p/sqrt(3))*cos(a), (p/sqrt(3))*sin(a) ] ];

positions = (layout == "triangle")
            ? tri_positions(pitch)
            : row_positions(n_rings, pitch);

xs = [ for (p = positions) p[0] ];
ys = [ for (p = positions) p[1] ];
cx = (max(xs) + min(xs)) / 2;
cy = (max(ys) + min(ys)) / 2;
plate_w = (max(xs) - min(xs)) + pocket_d + 2*plate_margin;
plate_d = (max(ys) - min(ys)) + pocket_d + 2*plate_margin;

front_y = cy - plate_d/2;   // edge the wire notches exit toward

// ---------- modules ----------
module base_plate() {
    translate([cx - plate_w/2, cy - plate_d/2, 0])
        cube([plate_w, plate_d, plate_th]);
}

module pocket(pos) {                 // recess that locates a ring
    translate([pos[0], pos[1], plate_th - pocket_depth])
        cylinder(h = pocket_depth + 0.1, d = pocket_d);
}

module peg(pos) {                    // center locator, rises from pocket floor
    if (use_center_peg)
        translate([pos[0], pos[1], plate_th - pocket_depth])
            cylinder(h = pocket_depth + peg_extra, d = ring_id - peg_clear);
}

module notch(pos) {                  // through-slot: solder relief UNDER the ring + wire channel to edge
    z0 = -1;
    h  = plate_th + 2;               // cut full thickness so the underside joint has clearance
    if (notch_dir == "front") {
        edge = front_y + 5;                              // plate front edge
        innr = pos[1] - pocket_d/2 + notch_under;        // reach under the ring
        translate([pos[0] - notch_w/2, edge, z0])
            cube([notch_w, innr - edge, h]);
    } else {                         // "back" -> toward the electronics shelf
        edge = cy + plate_d/2 - 5;                       // plate back edge
        innr = pos[1] + pocket_d/2 - notch_under;        // reach under the ring
        translate([pos[0] - notch_w/2, innr, z0])
            cube([notch_w, edge - innr, h]);
    }
}

module shelf_body() {
    if (shelf) {
        sy = cy + plate_d/2 + shelf_gap;
        // neck
        translate([cx - 9, cy + plate_d/2 - 0.1, 0])
            cube([18, shelf_gap + 0.2, plate_th]);
        // shelf plate
        translate([cx - shelf_w/2, sy, 0])
            cube([shelf_w, shelf_d, plate_th]);
    }
}

module shelf_holes() {
    if (shelf) {
        sy = cy + plate_d/2 + shelf_gap;
        for (hx = [ -shelf_w/2 + 5, shelf_w/2 - 5 ])
            for (hy = [ 5, shelf_d - 5 ])
                translate([cx + hx, sy + hy, -1])
                    cylinder(h = plate_th + 2, d = shelf_hole_d);
    }
}

module ghost_ring(pos) {             // preview only
    color([0.55, 0.55, 0.6, 0.45])
    translate([pos[0], pos[1], plate_th - pocket_depth])
        difference() {
            cylinder(h = ring_h, d = ring_od);
            translate([0,0,-1]) cylinder(h = ring_h + 2, d = ring_id);
        }
}

// ---------- assembly ----------
difference() {
    union() {
        base_plate();
        shelf_body();
    }
    for (p = positions) pocket(p);
    for (p = positions) notch(p);
    shelf_holes();
}
for (p = positions) peg(p);          // pegs added after the cut so they survive

if (show_rings) for (p = positions) ghost_ring(p);

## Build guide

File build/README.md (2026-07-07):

# Milestone 1 — Self-Reading Piezo PoC (build)

Hardware for **Milestone 1** of the χ_ν lift test: a small, self-contained object
that drives its own piezo rings, senses the response, and logs a reproducible
**coupling matrix** — the OPH "self-read receipt." No weighing and no lift claim
yet; this stage only proves that the self-reading object the experiment depends on
actually exists. Scope and decision rules live in
[`../test/DOCUMENT_A_prediction_ledger.md`](../test/DOCUMENT_A_prediction_ledger.md).

## Files

| File | What it is |
|---|---|
| [`MILESTONE_1_build.md`](MILESTONE_1_build.md) | The staged build plan — Stage 0 (characterise the rings on the Rigol) → Stage 1 (ESP32 logs the coupling matrix to Home Assistant). **Start here.** |
| [`electronics.md`](electronics.md) | Every subsystem as a chapter, each opening with a schematic: characterize the rings (Stage 0), system overview, controller/power/I²C, drive stage, ×120 amp + peak detector, TX select. **Rev 2 (2026-07-05):** real XIAO-C6 pinout, single 3.3 V rail, amplified RX chain, reset-after-burst capture — see the rev-2 notes in each chapter. |
| [`STAGE0_results_run1.md`](STAGE0_results_run1.md) | Lab-notebook record of the Stage-0 bench measurements (resonance, Q, coupling matrix, ring-2 finding). Versioned per run — copy to `…_run2.md` to repeat. |
| [`milestone1_jig.scad`](milestone1_jig.scad) | Parametric OpenSCAD carrier/ring jig — nonmagnetic, fixed ring spacing. |
| [`chi_nu_poc.yaml`](chi_nu_poc.yaml) | ESPHome firmware — drives the rings and publishes the timestamped C_ij matrix (+ shuffled control). |
| [`schematic/`](schematic/README.md) | Schematic sources (`*.sch`) and the generator that builds the `*.svg` diagrams embedded in `electronics.md`. |

## Regenerate the diagrams

```sh
cd schematic && make        # rebuild ../*.svg from the .sch sources
```

The `.sch` files are the source of truth; the `*.svg` are build artifacts.

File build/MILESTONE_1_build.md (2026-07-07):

# Milestone 1 — Self-Reading Piezo PoC (build v0)

**Goal:** prove the OPH **self-read loop** in hardware — a bounded object that
drives its own ports, senses the response, records it, and shows the records are
reproducible and predictive. **No weighing in this milestone.** No balance, no
torsion stage, no high voltage. Round piezo rings are fine (shape is irrelevant
to the self-read receipt).

Path shortcuts (`OPH:/`, `HOVER:/`, `ANS:/answer`, `ANS:/guide`) are defined in
`../test/DOCUMENT_A_prediction_ledger.md`. This build implements Milestone 1 of
`ANS:/guide` "Build Roadmap" and the §3.5 self-read gate of Document A.

---

## 1. What "done" looks like (exit receipt)

Milestone 1 is complete when you can produce, and log to Home Assistant:

1. **Coupling matrix C_ij** — drive port *i*, read every port *j*, store the
   response. Reproducible across repeats and **different from a shuffled/dummy
   control**.
2. **Same-port (or co-located) readback** — drive a port, then sense its own
   ringdown on the same port (or a fixed co-located partner). Response changes
   predictably with drive state.
3. **Stable logs** — every drive/read event timestamped, re-readable later.

That's it. ΔS, ACTIVE±/SHAM, top/bottom zoning, and the balance come in
Milestones 2–4.

How each piece maps to the OPH gate `S_coh = 1_self-read · R_U · P_U · C_U`:

| Build element | Gate it serves |
|---|---|
| Same-port / co-located drive+sense | `1_self-read` |
| Repeatable coupling matrix | `R_U` (record stability) |
| Past readings predict next reading | `P_U` (predictive boundary) — Milestone 2 |
| Structured, state-dependent coupling | `C_U` (visible coherence) |

### 1.1 Receipt acceptance thresholds (proposed pre-registration values)

`DOCUMENT_A` §3.5 requires the `R_U`/`C_U` tolerances to be **preregistered**
but leaves the numbers to the build. These are the proposed values — grounded
in the Run-1 Stage-0 measurements and the Chapter-5 signal chain — to freeze
(or amend, *before* the receipt run) in the ledger:

| # | Criterion | Pass threshold | Why this number |
|---|---|---|---|
| A1 | **Separation** (`C_U`) | every active off-diagonal cell mean ≥ **10×** the pooled shuffle σ, and ≥ **5×** the off-resonance mean | the weakest Run-1 cell (2 mV → ≈ 40–90 mV held ≈ 80–180 ADC LSB) sits ~40σ above the ADS noise floor (~1–2 LSB), so z ≥ 10 is conservative yet unambiguous |
| A2 | **Repeatability** (`R_U`) | per-cell CV ≤ **10 %** over ≥ **20** full matrices spanning ≥ **30 min** | Run-1 pair asymmetry was ~4 %; 10 % leaves room for the diode-knee tempco *with* interleaved controls (see A5 and `electronics.md` §5 noise budget) |
| A3 | **Reciprocity** | `\|C_ij − C_ji\|` ≤ **20 %** of the pair mean | Run-1 measured 4 % (10 vs 9.6 mV); 20 % catches a broken channel without failing honest part scatter |
| A4 | **Structure** | the distance gradient `C01 > C02` (row layout) holds in **every** repeat | the one ordering Stage 0 predicts independent of ring efficiency |
| A5 | **Controls, interleaved** | shuffle and off-resonance blocks are **interleaved with active blocks inside each repeat** (A-S-A-O pattern), not batched at the end; both control means < **1/10** of the weakest active cell | slow drift (thermal, battery, diode knee ≈ −1…−2 mV/°C) then cancels in the comparison instead of masquerading as signal — same ABBA logic as the eventual balance runs (`DOCUMENT_C` §1.3) |
| A6 | **Diagonals** | `C_ii` compared only against `C_ii` (repeats and controls), never against off-diagonals | tail-capture volts and peak-capture volts are different scales by design (`electronics.md` §5) |

A run that passes A1–A6 *is* the Milestone-1 receipt. A run that fails stays a
lab-notebook entry (`STAGE0_results_runN.md` style) — no partial credit, per
the ledger's receipt discipline.

---

## 2. Architecture (with your parts)

```
   ┌──────── self-contained PoC ────────┐
   │  Xiao ESP32-C6  (ESPHome)          │
   │   ├─ drive: LEDC PWM (50% duty) → buffer → TX piezo
   │   ├─ read : RX piezo → ×120 amp → peak-detector → ADS1015 (I2C: 4-ch mux + PGA)
   │   ├─ sensors: temp, IMU/accel, magnetometer, battery V
   │   └─ WiFi → Home Assistant (timestamped log = evidence bundle)
   │  3 piezo rings on a 3D-printed nonmagnetic jig
   │  1S LiPo on the XIAO BAT pads (later: untethered)         │
   └────────────────────────────────────┘
   Bench instrument (ground truth, not on the PoC):
     Rigol MHO954 — siggen drives, scope captures real ringdown/Q/phase
```

Two readout paths, on purpose:

- **ESP32 + peak-detector** gives one *amplitude* number per drive burst → the
  coupling-matrix entries C_ij. Slow ADC is fine because the detector holds the
  peak. This is the self-contained PoC path.
- **Rigol scope** gives the full fast waveform (ringdown shape, Q, phase). Use it
  to find resonances and to validate that the peak-detector numbers are real.
  The scope is *bench ground truth*, not part of the flying object.

> Why ESPHome/WiFi is the right call: for the later balance run the PoC must have
> **no force-bearing cable**. Battery + WiFi logging satisfies that for free, and
> Home Assistant gives you clean, timestamped, exportable records (the OPH
> "evidence bundle", `ANS:/answer` §3.12). What you build now is the logging spine
> you'll reuse at the balance.

---

## 3. Build during the day — three stages

### Stage 0 — Characterize the rings on the Rigol (no custom electronics)

You can do this immediately with what's on the bench.

1. Solder a thin wire to each face of one piezo ring (the two silvered
   electrodes). Repeat for all three.
2. **Find resonances:** Rigol siggen → ring (through ~100 Ω series). Sweep
   1 kHz → 1 MHz while watching the current/voltage or the ring's own response on
   the scope. Expect strong modes somewhere in **~20 kHz–500 kHz** (a radial mode
   lower, a thickness mode near a few hundred kHz). Record every resonance f and
   its sharpness (Q).
3. **Ringdown (same-port self-read, manual version):** drive a short burst
   (siggen burst mode, ~20–100 cycles at a resonance), then watch the ring's own
   voltage decay on the scope after the drive stops. That decay *is* the self-read
   signal. Note amplitude and decay time.
4. **Cross-coupling (coupling matrix, manual version):** mount two rings close
   together (touching faces or on a shared plate). Drive ring A, scope ring B.
   Record amplitude/phase for each ordered pair. This is C_ij by hand.

**Stage 0 output:** a table of resonances, ringdown times, and a 3×3
cross-coupling matrix measured on the scope. This already tells us the rings are
usable and fixes the drive frequency for Stage 1. Genuinely useful even if we
stop here for the day.

### Stage 1 — ESP32 reads its own coupling matrix (ESPHome + HA)

Turn the manual measurement into an automated, logged, self-contained loop.

1. **Drive stage:** ESP32 LEDC PWM pin (50 % duty square) → S8050/S8550 push-pull
   → ~100 Ω → TX ring, all on the 3.3 V rail (the swing is set by the base drive,
   not the rail — see `electronics.md` ch. 4).
2. **Read stage (per RX ring):** RX ring → **two-stage ×120 amplifier**
   (MCP6022; the Stage-0 coupled signals are only 2–10 mV — a bare diode cannot
   see them) → Schottky envelope detector (1N5819 → 10 nF hold, 10 MΩ bleed) →
   ADC. A GPIO-driven transistor across the hold cap **resets** it right *after*
   each burst, so each reading is pure post-drive ringdown, never burst
   feedthrough. (Full design + values: `electronics.md` ch. 5.)
3. **Channel select + digitize:** feed each RX peak-detector into a channel of the
   **GY-ADS1015** (I2C; 4-channel internal mux + programmable gain). One I2C ADC
   reads all rings and amplifies tiny peaks — no CD4051, no scarce ESP ADC pins.
4. **State machine (ESPHome script):** for each TX ring → fire a burst at the
   Stage-0 resonance (LEDC at 50 % duty for ~1 ms ≈ 44 cycles @ 43.5 kHz, then
   off) → open all TX switches → **reset pulse ~120 µs after drive-off** → the
   hold caps recharge from pure ringdown → read each RX peak through the mux →
   publish all C_ij to Home Assistant with a timestamp and a run/state label.
   The diagonal C_ii uses a second burst with a ~3 ms tail delay (the driven
   ring saturates its own ×120 amp until the ringdown decays into range).
5. **Repeat** the full matrix many times → that gives R_U (stability). Run two
   controls: **shuffled** (no drive at all — the noise floor) and
   **off-resonance** (full drive at ~29 kHz — same electrical feedthrough, no
   resonance). **Interleave them**: each repeat cycle runs
   active → shuffle → active → off-resonance (A-S-A-O), so slow drift cancels
   in the comparison (threshold A5). Log board temperature with every sweep —
   the weakest cell moves ~2–5 %/°C through the Schottky knee
   (`electronics.md` §5, noise budget).

**Stage 1 output:** automated, timestamped C_ij logged in HA, passing the §1.1
thresholds A1–A6. **That is the Milestone 1 receipt.**

### Stage 2 — preview (Milestone 2, not today)

Designate one ring "top zone", one "bottom zone" (mount them vertically separated
on the jig); add the ACTIVE+ / ACTIVE− / SHAM drive patterns and the
predictive-boundary test (records at cycle *t* predict readout at *t+1* better
than shuffled). That produces the signed ΔS receipt. We'll write its own doc.

---

## 4. Circuit detail (one TX + one RX channel)

```
ESP32 LEDC ──┬── S8050/S8550 push-pull (3.3V rail) ──[100Ω]── TX ring ──┐
             │                                                           │ (coupling)
            GND ───────────────────────────────────────────────────────GND
                                                                         │
RX ring ──[C_in 10n]──[×21]──[×5.7]──[100Ω]──[C_c 100n]──[1N5819]──┬── ADS1015 AINx
   │                  (MCP6022, biased mid-rail)                     │
 [R_ref 1M]                                     [Chold 10nF]──┬──[Rbleed 10M]
   │                                                          │
  GND                                            [reset NPN + 100Ω, GPIO21]
```

One RX amp+detector per ring → ADS1015 AIN0..AIN2 (its internal mux + PGA select
each channel over I2C). **The ×120 amp is not optional** — Stage 0 measured the
coupled signals at 2–10 mV, below any Schottky's knee; the old amp-less sketch
could not read the off-diagonals. Full schematic + values: `electronics.md`
ch. 5 / `peak_detector.svg`.
Keep all grounds common and short. No voltages here exceed a few volts — ordinary
bench safety only. (High-voltage piezo drive, if ever needed, is a later milestone
with its own safety doc, `HOVER:/docs/safety.md`.)

---

## 5. ESPHome config — skeleton

Not complete firmware, but the shape (fill pins from your wiring):

```yaml
esphome:
  name: chi-nu-poc
esp32:
  board: seeed_xiao_esp32c6      # XIAO C6; a XIAO C3 needs its own pin map
wifi: { ssid: !secret wifi_ssid, password: !secret wifi_password }
api:                              # Home Assistant logging
logger:

output:
  - platform: ledc               # drive tone
    pin: GPIO2                   # D2
    id: drive_pwm
    frequency: 43500Hz           # Stage-0 resonance (recheck f_s vs f_p!)

switch:
  - platform: gpio               # peak-detector reset (all channels)
    pin: GPIO21                  # D3
    id: pk_reset

i2c: { sda: GPIO22, scl: GPIO23 }   # the C6's real I2C pins (D4/D5)

ads1115:                         # ESPHome has no ads1015 platform —
  - address: 0x48                # the ads1115 hub drives the ADS1015

sensor:
  - platform: ads1115            # one channel; repeat A0..A2
    multiplexer: A0_GND
    gain: 1.024                  # amped chain → held peaks ~0.05–1 V
    resolution: 12_BITS          # <- this makes it an ADS1015
    id: rx_peak0
    update_interval: never       # read on demand from the script
  # add rx_peak1..2 on A1_GND/A2_GND
  # I2C IMU + magnetometer + temperature + battery-voltage sensors here

script:
  - id: sweep_matrix
    then:
      - repeat:
          count: 3               # for each TX ring i
          then:
            # IMPORTANT: output.turn_on would mean 100% duty = DC, not a tone —
            # always burst with set_level 0.5 (50% square) / 0.0.
            - output.set_level: { id: drive_pwm, level: 50% }
            - delay: 1ms                     # ≈ 44 cycles @ 43.5 kHz
            - output.set_level: { id: drive_pwm, level: 0% }
            # reset AFTER the burst (dump feedthrough, hold pure ringdown);
            # the ~100 µs pulse timing lives in a lambda in the real config
            - switch.turn_on: pk_reset
            - switch.turn_off: pk_reset
            - delay: 2ms                     # settle
            # for each RX ring j: component.update rx_peak, log C_ij
```

This is only the *shape* — the real, complete config is
[`chi_nu_poc.yaml`](chi_nu_poc.yaml) (µs-precise reset timing in lambdas, the
two-burst diagonal capture, the shuffled + off-resonance controls, and the
matrix publishing). Ringdown-shape / Q / phase capture wants custom ESP-IDF
firmware or the Rigol — Milestone-2 territory.

---

## 6. Parts: have vs. order

### Core self-read electronics — fully covered by your stock

| Build block | Use |
|---|---|
| Controller + logging | Xiao ESP32-C6 + ESPHome → Home Assistant (stock) |
| **ADC + channel mux + gain** | **GY-ADS1015** (I2C, 4-ch internal mux, PGA) — removes both the CD4051 *and* the ESP internal-ADC limits (stock) |
| Drive buffer | S8050 + S8550 complementary emitter-follower (or 2N3904/2N3906) — **off the 3.3 V rail** (the rail doesn't set the swing; the base drive does) |
| Drive series R | 100 Ω (1206, stock) |
| **RX amplifier ×120 (×3)** | **MCP6022 / TLV2372 dual RRIO op-amps — ORDER 3.** The measured couplings are 2–10 mV; without this amp the detector reads nothing. LM358 (stock) works as a reduced-gain fallback (~×55, less stable) |
| Peak-detect diode | **1N5819 (SS14)** Schottky — *not* 1N4007 (too slow / high-C) (stock) |
| Hold cap | **10 nF** (1206, stock) — τ = 100 ms with the 10 MΩ bleed |
| Bleed resistor | **10 MΩ** (1206, stock) |
| Detector reset | small NPN (S8050 / 2N3904) across the hold cap via 100 Ω, GPIO21-driven (stock) |
| Power | **one 3.3 V rail from the Xiao** (USB-C bench / 1S LiPo on BAT pads untethered). The 7805/Mini560/2S chain is dropped — 7805 dropout and AMS1117 thermals made it a trap; 5 V is optional for LM358/LM386 experiments only |
| Battery + jig | 1S LiPo + 3D print |
| Precision scale | **not needed for Milestone 1** (torsion-vs-precision decision is Milestone 3/4) |

Everything except the three MCP6022/TLV2372 is on hand; the LM358 fallback lets
you get first light before they arrive.

### Order — sensors only (deferrable past the first receipt)

| Part | Why | When |
|---|---|---|
| I2C IMU (MPU6050 / LSM6DS3) | vibration / accel log | M1 sensor; C_ij works without it |
| I2C magnetometer (QMC5883L) | magnetic-artifact log | essential at the balance, not for the self-read receipt |
| DS18B20 temperature probe | thermal log | M1 nice-to-have; meanwhile read a 1N4148 forward voltage on a spare ADS1015 channel as a crude temp |

### Use-this-not-that notes
- **ADS1015 + ESPHome:** use the **`ads1115:` hub with `resolution: 12_BITS`** —
  ESPHome has no separate ads1015 platform; the ads1115 component drives the
  ADS1015 (verified against the ESPHome docs, 2026-07).
- **Amplify before detecting, not after:** a follower *behind* the diode fixes
  droop but not sensitivity — and with C_hold = 10 nF (τ = 100 ms) droop is a
  non-issue anyway. The gain must come **before** the 1N5819, which is why the
  LM358's role changed from "optional buffer" to "fallback front-end amp".
- **LEDC bursts:** `output.turn_on` = 100 % duty = DC. Always burst with
  `set_level 0.5` / `0.0`.
- **LM386** = optional drive amp for the radial mode only (needs ≥4 V — the
  optional bench 5 V); too slow for a ~400 kHz thickness mode.
- **LM339** on hand if you later want a zero-cross / phase comparator.
- **NE555** could self-generate the drive tone, but ESP-LEDC bursts are better
  (commanded timing + state labels).

### Order (nice-to-have / next milestones)
| Part | Why |
|---|---|
| **3× MCP6022 (or TLV2372)** | the ×120 RX front ends — the one genuinely required order (LM358 = interim fallback) |
| 3–5 **more matching piezo rings** | richer coupling matrix, dedicated top/bottom zones |
| **74HC4066** | low-R_on (~50 Ω) drop-in for the CD4066 at 3.3 V (optional) |
| Small **gate driver / op-amp drive buffer** | stronger, cleaner drive than a bare GPIO |
| **MicroSD breakout** | onboard logging fallback for untethered balance runs (WiFi already covers it) |
| Nonmagnetic plate (acrylic / aluminum) | dimensionally stable carrier vs printed jig |
| INA219 / resistor divider | battery voltage/current monitor for the receipt |

---

## 7. 3D-printed jig (print today)

- A flat plate with three recessed pockets for the rings, fixed spacing, plus a
  shelf for the Xiao + protoboard. PETG or PLA is fine for Milestone 1.
- Keep it **nonmagnetic** (no steel inserts) — habit for later balance runs.
- Make ring spacing a parameter; you'll want to vary coupling later.
- For the Stage-2 top/bottom version, print a variant that holds one ring high and
  one low on a vertical web.

---

## 8. Order of operations today

1. Solder leads to the 3 rings.
2. **Stage 0** on the Rigol → resonance table + ringdown + 3×3 cross-coupling. (No
   ordered parts needed — pure win for the day.)
3. Print the jig.
4. Flash ESPHome to the Xiao; verify WiFi → Home Assistant; check the LEDC drive
   frequency on the Rigol (your scope confirms the ESP32 makes the right tone).
5. Breadboard one TX + one RX peak-detector channel; confirm the ESP reads a peak
   that tracks the scope. (This is the first real self-read.)
6. When the Schottky/mux/op-amp arrive: expand to 3 channels, run `sweep_matrix`,
   log C_ij to HA, add the shuffled control.

Stages 0, 3, 4, and 5 need **only what you already have** — that's a full, useful
day of building before any parts arrive.

---

## 9. What this does *not* claim — and how it hooks into the proof chain

Milestone 1 produces a self-read receipt, nothing more. It does **not** weigh
anything, does **not** test lift, and says nothing about χ_ν yet. Its value:
it builds (and proves) the self-reading object that the whole experiment depends
on — and, per the reasoning in `ANS:/reply_to_bmu.md`, the magnitude of the
record-level ΔS it later produces is exactly what lets us check the ΔS-estimator
bridge empirically.

Where each piece sits in the proof chain
(`../proof_chain/OPH_CORE_MINIMAL_PROOF_CHAIN.md`, v6):

- **What M1 instantiates.** The receipt is the *operational input* to
  `S_coh = 1_self-read·R_U·P_U·C_U` (`DOCUMENT_A` §3.5). The record-side
  object that quantity feeds — the finite coherent-source generator, whose
  increment is what the collar prices — exists as a machine-checked formal
  object (`proof_chain/formal/OPHProofChain/DeltaSBridge.lean`, T17). M1
  supplies the *receipts*; what number of record-activations corresponds to
  how much gravity-side ΔS is exactly the open gap **G9** — which is why a
  later null bounds only the product χ·ΔS.
- **What M1 tests of the theory: nothing.** Both the proven OPH core and the
  conditional χ_ν continuation predict that a competently built self-read
  loop passes A1–A6 — this milestone is instrumentation, and a failure here
  would say "build problem", not "theory refuted". The first
  theory-adjudicating step is the Milestone-4 weighing, whose conversion
  constants are theorem-form (`LedgerNumerics.lean`, T24: the 5.50×10⁸ N
  per unit Δν, the 9.1×10⁻¹⁷ lock-in floor) and whose expected outcome is
  **NULL** by the conservation cage (`EnergyCage.lean`, T10; chain §5) —
  a genuine DETECT must arrive with a ≥ 3.5 MJ-scale energy-ledger entry.
- **Why build it anyway.** A null with a *passing* self-read gate is
  informative (it prices χ·ΔS at ≤ 9.1×10⁻¹⁷ on this coupon); a null on a
  coupon that failed the gate is worthless — OPH predicts null there too
  (`DOCUMENT_A` §3.5). M1 is what makes the eventual null *mean something*.

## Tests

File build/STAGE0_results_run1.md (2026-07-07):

# Stage 0 — bench characterization results (Run 1)

Lab-notebook record of the Stage-0 ring characterization: resonance, Q, and the
ring-to-ring coupling matrix measured on the Rigol **before** any custom
electronics. This is the procedure in
[`electronics.md` §1 — Characterize the rings (Stage 0)](electronics.md#1-characterize-the-rings-stage-0)
and Stage 0 of [`MILESTONE_1_build.md`](MILESTONE_1_build.md). Scope and decision
rules live in [`../test/DOCUMENT_A_prediction_ledger.md`](../test/DOCUMENT_A_prediction_ledger.md).

| | |
|---|---|
| Run | **1** |
| Date | 2026-06-06 |
| Operator | _____________ |
| Stage | 0 (characterization only — **no weighing, no lift claim**) |
| Status | mostly complete; open items in §6 |
| Rings | 3× PZT, OD 38 mm / ID 14.8 mm / 5 mm (per [`milestone1_jig.scad`](milestone1_jig.scad)) |
| Layout | `row` (ring 0 — ring 1 — ring 2 in a line; 0↔1 and 1↔2 adjacent, 0↔2 far) |

> **This is a versioned document.** Run 1 is the first build, with the
> heat-degraded ring 2 (see §5). To repeat the experiment — e.g. with fresh
> piezos — **copy this file to `STAGE0_results_run2.md`** and refill the tables,
> rather than overwriting Run 1. Keep each run as its own snapshot.
>
> If any later run produces a result that hints at new physics, interpretation is
> **not** decided here — it is governed by the pre-registered decision rule in
> [`../test/DOCUMENT_A_prediction_ledger.md`](../test/DOCUMENT_A_prediction_ledger.md) Part 5.
> This document only records what was measured.

---

## 1. Equipment & setup

- **Instrument:** Rigol MHO954 (built-in generator GI + oscilloscope).
- **Rig:** series-R current sense per
  [`electronics.md` §1](electronics.md#1-characterize-the-rings-stage-0) —
  GI → **R_sense 100 Ω** → ring hot; ring cold → common GND.
  Diagram: [`stage0_characterization.svg`](stage0_characterization.svg).
- **Probes:** ×10 (10 MΩ) on CH1 (drive node) and CH2 (piezo / read node).
- **Grounding:** single **star** — all three ring cold faces bussed to one common
  point (TX return kept off the RX ground legs). Same poled face = ground on all
  rings.
- **Ring leads:** twisted pairs (salvaged network cable), one pair per ring.
- **Generator note:** this unit has **no dedicated Sweep/Burst tab** (only Basic
  waveforms + Modulation AM/FM/PM). Resonances in this run were found by **manual
  frequency-knob scan**. (Automated alternatives if needed: FM + ramp modulating
  wave = a sweep; AM + 100 % square = a burst train for ringdown.)

---

## 2. Resonance (`f_r`) — Use 1

Manual sine scan, ~2 Vpp into R_sense, watching CH2 for the amplitude peak +
phase flip.

| Ring | `f_r` (amplitude peak) | Notes |
|---|---|---|
| 0 | **43.5 kHz** | sharp peak; phase flip ~43.6 kHz |
| 1 | **43.5 kHz** | sharp peak |
| 2 | **43.5 kHz** | resonates at same `f_r`, but weak (see §5) |

- **Drive frequency adopted for Stage 1: 43 500 Hz** (replaces the placeholder
  `frequency: 50000Hz` in [`chi_nu_poc.yaml`](chi_nu_poc.yaml) once confirmed in
  firmware).
- The amplitude peak (43.5 kHz) and the sharpest phase flip (~43.6 kHz) differ by
  ~0.2 % — normal for a piezo (the flat electrode capacitance C0 shifts the
  zero-phase point off the response maximum). **Drive at the peak** for maximum
  energy into the ring.

### 2a. Erratum (2026-07-05) — the 43.5 kHz "amplitude peak" is f_p, not f_s

*(Annotation; the recorded numbers above are untouched.)* In this rig (drive
through R_sense = 100 Ω, CH2 across the ring) a **CH2 amplitude *peak* is the
parallel/anti-resonance `f_p`** (ring impedance maximum, minimum current). The
**series resonance `f_s`** — impedance minimum, maximum current, and the
frequency at which a low-impedance source pumps the most energy into the ring —
shows as a **CH2 *dip* a few percent *below* `f_p`** and was not logged in this
run. Consequences:

- The interpretive note above ("drive at the peak for maximum energy") has it
  backwards for a series-driven TX: near **`f_s`** the drive current, and with
  it the mechanical excitation, is maximal. The `k_eff²` of these PZT rings puts
  `f_p − f_s` at a few % of f_r, i.e. **many bandwidths** (BW = f_r/Q ≈ 0.6 kHz).
- The §4 coupling matrix was therefore measured at a drive frequency that is
  likely several bandwidths above the optimum — the 10/5/2 mV values are valid
  *relative* numbers for 43.5 kHz but probably **undersell the achievable
  coupling by a factor of a few**.
- The §5 ring-2 conclusion (≈50 % efficiency, both directions) is a *ratio* at
  fixed frequency and is **unaffected**.
- **Action for Run 2 / Stage 1:** log the CH2 dip (`f_s`) per ring, then sweep
  the burst frequency between `f_s` and `f_p` and freeze `drive_freq` at the
  point of maximum coupled RX amplitude (procedure now in
  [`electronics.md` §1](electronics.md#1-characterize-the-rings-stage-0)).

---

## 3. Quality factor (`Q`) — Use 1

From the −3 dB width of ring 0's resonance peak:

| Quantity | Value |
|---|---|
| `f_r` | 43 500 Hz |
| −3 dB (0.707·max) low | ≈ 43 200 Hz |
| −3 dB (0.707·max) high | ≈ 43 770 Hz |
| Δf | ≈ 570 Hz |
| **Q = f_r / Δf** | **≈ 76** (call it ~75, approximate) |

> The response fluctuated a little during the measurement (probable pickup on the
> high-Z node), so the −3 dB points wander a bit around the values above; treat
> Q ≈ 75 as a ballpark. A burst of ~50–100 cycles is appropriate (energy builds
> over ~Q cycles). Cross-check via ringdown later: `Q = π·f_r·τ`.

---

## 4. Cross-coupling matrix `C_ij` — Use 3

Drive one ring at 2 Vpp / 43.5 kHz through R_sense; read the **peak amplitude of
the coupled sine** at another ring (×10 probe, same 43.5 kHz). Raw scope
millivolts — **relative, uncalibrated** (sufficient for the matrix and for the
shuffled-control comparison in Milestone 1).

**TX (row) → RX (column), mV peak @ 2 Vpp, 43.5 kHz** (values averaged for precision):

| | RX ring 0 | RX ring 1 | RX ring 2 |
|---|---|---|---|
| **TX ring 0** | — (self) | **10** | 2 *(far pair)* |
| **TX ring 1** | **9.6** | — (self) | 5 *(ring 2 weak)* |
| **TX ring 2** | 2 | 5 | — (self) |

- **Fully reciprocal:** C(0→1)=10 / C(1→0)=9.6, C(0→2)=C(2→0)=2,
  C(1→2)=C(2→1)=5. Symmetric within measurement scatter → the rig is sound;
  the asymmetries are in the parts, not the setup.
- **Distance gradient confirmed** (the `row`-layout prediction C01 > C02):
  adjacent pair 0↔1 ≈ **9.8 mV** vs far pair 0↔2 ≈ **2 mV**.
- **Internal consistency / decomposition.** Modeling C_ij ≈ (distance factor)·e_i·e_j
  with a per-ring efficiency `e`:
  - *Ring 2 efficiency:* the two adjacent pairs share ring 1, so
    e₂/e₀ ≈ C12/C01 = 5/10 ≈ **0.5** → ring 2 ≈ half (matches §5).
  - *Plate falloff:* the far/adjacent geometric ratio ≈ **0.4** from two
    independent routes (C02/C01 ÷ efficiency, and C02/C12) — they agree, so the
    simple model holds and the 2 mV far reading is just geometry × half-strength ring 2.
- The structure (strong 0↔1 pair, weak ring-2 row/column, clean distance gradient)
  is well-defined and far above any plausible shuffled-control baseline → good
  footing for the Stage-1 receipt.
- Diagonals (same-port self-read C00/C11/C22) **not measured on the scope** —
  they need the reset-after-drive trick and are a Stage-1 firmware step
  ([`electronics.md` §5](electronics.md#5-peak-detector-rx)).

---

## 5. Finding: ring 2 is heat-degraded (~50 %) — depoling, confirmed

**Cause:** during soldering, a ~3×2 mm patch of ring 2's electrode coating was
overheated, blistered, and de-coated; it was bridged with a small ring of solder
to the surrounding intact electrode. The prolonged heat **partially depoled** the
ceramic — confirmed by the C0/ESR measurement below.

**Evidence (controlled comparison):** driving the **center ring (ring 1)**, its
two neighbors are at **equal distance**, yet:

- ring 1 → ring 0 = **9.6 mV**
- ring 1 → ring 2 = **5 mV**

Same driver, same geometry, ~half the signal (e₂/e₀ ≈ 0.5) ⇒ the deficit is **ring 2 itself**,
not the layout. The reduction appears in **both** directions (ring 2 weak as TX
*and* as RX), consistent with **partial depoling** of the ceramic from the
soldering heat: piezoelectric coupling is reciprocal, so lost activity lowers TX
and RX equally. `f_r` is unchanged (set by mechanical dimensions, which the heat
did not alter) — only the electromechanical conversion dropped. The clean, stable
5 mV sine (not flaky/noisy) argues against a bad joint and toward genuine
depoling.

**Confirmed by C0 / ESR (MTester V2.07):** ring 0 = 2264 pF, ring 1 = 2260 pF,
ring 2 = 2314 pF; **ESR = 17 Ω on all three.** Ring 2's capacitance is normal (if
anything marginally *higher*, not lower) and its ESR matches the others, so
electrode area, dielectric, and contact resistance are all intact. A lost-area or
bad-joint failure would have dropped C0 or raised ESR — neither happened. With
C0, ESR, and `f_r` all normal but coupling halved in both directions, **reduced
piezoelectric activity (partial depoling) is the only consistent explanation.**
(Measurement valid despite the still-bussed grounds: the other rings' hot leads
were open, forming no return path.)

**Disposition:** ring 2 is **still usable for Milestone 1** — 5 mV @ 43.5 kHz is
well above noise and reproducible, and the self-read receipt only needs a stable
matrix clearly above the shuffled control. Ring 2 is flagged as the deliberately
**weak row/column**; do **not** use it as a reference ring. Replace with a fresh
piezo when stock arrives (→ Run 2).

---

## 6. Open items / TODO

- [x] ~~**C0 (static capacitance)** of all three rings~~ — done (MTester V2.07):
  ring 0 = **2264 pF**, ring 1 = **2260 pF**, ring 2 = **2314 pF**; ESR = **17 Ω**
  on all three. All equal within scatter (~2.26 nF, validating the ≈2 nF design
  assumption); ring 2 not lower ⇒ **§5 depoling confirmed**, not electrode/contact loss.
- [x] ~~Fill the missing matrix cell **C(2→0)** and re-read C(0→2)~~ — done (§4):
  both = 2 mV, reciprocal; far/adjacent ratio ≈ 0.4 (consistent with geometry).
- [ ] Diagonals C00/C11/C22 (same-port self-read) — **implemented** in
  [`chi_nu_poc.yaml`](chi_nu_poc.yaml) (rev 2: two-burst capture, reset after
  drive-off, `diag_tail_ms ≈ 3 ms` so the ×120 amp is back in range);
  pending bench validation (diagonal should track drive and sit above the
  shuffle baseline). Tune `diag_tail_ms` if it reads rail (too early) or ~0
  (too late).
- [ ] Ringdown `τ` per ring → independent Q (`Q = π·f_r·τ`), cross-check §3.
- [ ] **Log `f_s` (CH2 dip) per ring and re-measure C_ij at the
  max-coupling frequency** — see erratum §2a; expect larger values than §4.
- [ ] Per-ring `f_r` to finer resolution (all read 43.5 kHz at scan resolution).

---

## 7. Status & next step

Stage 0 essentially done: rings characterized (`f_r ≈ 43.5 kHz`, `Q ≈ 75`), a
clean reciprocal coupling matrix obtained, and one degraded ring identified and
understood. **No weighing, no lift claim** — that is by design for this stage.

**Next:** Stage 1 — flash [`chi_nu_poc.yaml`](chi_nu_poc.yaml) (drive 43 500 Hz),
have the ESP32 log the coupling matrix to Home Assistant, and show it stands above
the shuffled control. That logged, reproducible matrix is the Milestone-1
**self-read receipt** ([`MILESTONE_1_build.md` §1](MILESTONE_1_build.md)).

**Run 2 trigger:** repeat with fresh piezos (healthy ring 2) — copy this file to
`STAGE0_results_run2.md`.

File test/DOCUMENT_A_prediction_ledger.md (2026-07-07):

# Document A — Prediction Ledger (Pre-Registration)

**χ_ν coherent-matter lift test · BTTF-chi mechanism**

| | |
|---|---|
| Status | DRAFT — not yet locked |
| Version | 0.2.2 (2026-07-07; v0.2/v0.2.1 and the v0.1 correction pass are in git) |
| Date created | 2026-06-02 |
| Date locked | _____________ (no edits to Parts 1–4 after this date) |
| OPH theory representative (predictions) | _____________ |
| Experimenter (apparatus) | _____________ |
| Lock hash (sha256 of this file at lock) | _____________ |

> **What changed in v0.2.** The 2026-06-02/03 question-and-answer history is
> compressed to its resolved state; all source line references are re-anchored
> to the current tex files; a numeric error in the §3.4 sanity rail is fixed;
> and the conservation-law constraints are disclosed up front (§1.9). The
> decision rule (Part 5) is unchanged in substance. **v0.2.1 (2026-07-06):**
> after the OPH-side `proof_chain/AUDIT_RESPONSE.md` and the July paper consistency pass,
> all `chi_nu_susceptibility_bounds.tex` anchors are re-anchored to the
> restructured file (now 1860 lines, Tier B split into B0/B1, lemmas L1–L7),
> and §1.3/§1.4/§1.7 reflect the new theorem surface. Audit trail:
> `proof_chain/AUDIT_RESPONSE.md` and git history (which also holds the former
> `CORRECTIONS_2026-07-05.md`, absorbed at the v3 reorganization).
> **v0.2.2 (2026-07-07): status-citation notes only.** The proof chain is now
> v4: its `formal/` Lean tree machine-proves the whole mathematical side of
> the chain (0 `sorry`, incl. the OPH core's three, discharged in an
> attributed in-repo copy). §1.4, §1.5 and §1.9 gain machine-checked-status
> notes pointing at `proof_chain/formal/`. **No number, threshold, disclosure
> or decision-rule text changed.**
> **v0.2.3 (2026-07-07): the G10-convention naming and one erratum.** Per the
> adversarial audit (F15/F28): §1.9 restructured to name the **G10-convention**
> pricing as the decision-layer hypothesis it is, with the theorem-grade
> anchors stated beside it (machine-checked in v7: `anchor_ordering`); the
> printed battery-coupon ceiling corrected from "≲ 1×10⁻¹¹ (≈ 0.5 gf)" to
> "≲ 1.1×10⁻¹¹ (≈ 0.58 gf)" (erratum note in place, `battery_coupon_bounds`).
> One number changed (the erratum, in the unsafe-to-omit direction); no
> threshold or decision-rule text changed. §1.4's hypothesis family now reads
> L0–L7 (L0 = the named collar-shape clause).

## Source repositories (path shortcuts)

| Shortcut | Repository (cloned dir) | Upstream | Typical subpaths |
|---|---|---|---|
| `OPH:/` | `observer-patch-holography/` | https://github.com/FloatingPragma/observer-patch-holography | `OPH:/paper/`, `OPH:/extra/`, `OPH:/cosmology/`, `OPH:/LEAN/` |
| `HOVER:/` | `hoverboard/` | https://github.com/muellerberndt/hoverboard | `HOVER:/docs/`, `HOVER:/bom/` |
| `ANS:/` | `chi_nu_test/communication/` (absorbed into this repo 2026-07-06; history at https://github.com/dmatscheko/hoverboard-experimental-precursor) | Q&A with OPH-side research | `ANS:/`, `ANS:/input_from_bmu/` |
| `ANS:/answer` | `communication/input_from_bmu/chi_nu_lift_test_answer_and_experiment.pdf` | OPH-side answer + balance protocol (2026-06-03) | cited by § number |
| `ANS:/guide` | `communication/input_from_bmu/hacking-the-simulation-anti-gravity-exploit.pdf` | OPH-side research draft (2026-06-03) | cited by chapter title |

The trailing `:` marks a prefix as a repo shortcut, never a real directory.
Our own repo is laid out as **`test/`** (the pre-registration ledgers
`DOCUMENT_A/B/C` — this file's directory), **`proof_chain/`** (the audit work:
`OPH_CORE_MINIMAL_PROOF_CHAIN.md`, `AUDIT_RESPONSE*.md`, corrections log),
**`build/`** (Milestone-1 hardware) and **`communication/`** (the Q&A with the
OPH side, = `ANS:/`). Bare filenames refer to files in the same directory;
cross-directory prose uses repo-root-relative paths.

## Purpose

This document fixes, **before any data is taken**, exactly what the χ_ν lift
mechanism predicts for our coupon, so that neither side can re-interpret the
result after the fact. It does three things:

1. **Imports the OPH math verbatim** (Parts 1–2) with file/line provenance,
   so the prediction is *OPH's*, not our paraphrase.
2. **Records the inputs only the OPH side can supply** (Part 3) — now filled
   with the agreed 2026-06-03 answers.
3. **Derives the falsifiable predictions** (Part 4), including the detection
   threshold and the bound a null places on the OPH coefficient.

Parts 1, 2 and 4 are computed/imported and fixed at lock; Part 3 is the only
place free choices enter. The pre-registered decision rule is Part 5.
Background: the standing of every imported claim (proven / conditional /
asserted) is assessed in [`proof_chain/OPH_CORE_MINIMAL_PROOF_CHAIN.md`](../proof_chain/OPH_CORE_MINIMAL_PROOF_CHAIN.md);
open questions and credit are ledgered in
[`DOCUMENT_B_critique_ledger.md`](DOCUMENT_B_critique_ledger.md); the
apparatus, run matrix and error budget are
[`DOCUMENT_C_run_matrix_and_error_budget.md`](DOCUMENT_C_run_matrix_and_error_budget.md).

---

## Part 1 — Imported constants and equations (OPH math)

All references are to the cloned repositories; equation tags are the LaTeX
labels in the source. Line anchors verified 2026-07-06 (post-restructure).

### 1.1 Fixed physical constants

| Symbol | Value | Source |
|---|---|---|
| g | 9.80665 m s⁻² | `OPH:/extra/chi_nu_susceptibility_bounds.tex:1359` |
| G | 6.67430×10⁻¹¹ m³ kg⁻¹ s⁻² | `:1360` |
| C_geom ≡ g²/(4πG) | **1.146637×10¹¹ N m⁻²** | `:1347–1361` (cor. `geometric-ceiling`) |
| 4πG | 8.387173×10⁻¹⁰ m³ kg⁻¹ s⁻² | derived |

### 1.2 OPH readout numbers

| Symbol | Value | Source |
|---|---|---|
| P (screen-cell area a_cell/ℓ★², the OPH "pixel-area ratio") | 1.630968209403959 | `OPH:/extra/chi_nu_susceptibility_bounds.tex:1109–1116` (eq. `z6-reserve`) |
| P/24 | 0.06795700872516496 | same |
| χ_can^exact = e^(−P/24) | **0.9343006394893864** | `:1190–1210` (cor. `chi-can-exact`) |
| u₀ (reference energy density) | 8.5×10⁻¹⁰ J m⁻³ | `:1462, :1620` (table captions only) |

> **Provenance (refined 2026-07-06 after tracing the code).** The corpus holds
> **two** values of P on two labeled branches
> (`OPH:/extra/fine_structure_constant_derivation.tex`; executable in
> `OPH:/code/P_derivation/`, reproduced by us): a genuine zero-empirical-input
> fixed-point solver outputs **P_root = 1.6309721** with α⁻¹ = 136.9948 (~300
> ppm from measurement), while the published **P = 1.630968209403959… is by
> definition φ + √π/137.035999177** — i.e. a restatement of the measured
> CODATA α (the repo's own calibration file marks `external_input_used: True`).
> The value imported here is the published (CODATA-calibrated) one, per the
> OPH side's χ_ν convention. **This choice is immaterial for this experiment:**
> the two branches shift χ_can = e^(−P/24) by only ~1.6×10⁻⁷ relative
> (0.93430064 vs 0.93430049), far inside every tolerance in Part 4. u₀ is a
> declared reference density. (Arithmetic verified: P/24, e^(−P/24), C_geom as
> quoted. Full adjudication: `proof_chain/AUDIT_RESPONSE_REVIEW.md` §P.)

### 1.3 The continuation law (Tier B)

The local response law the mechanism rests on
(`OPH:/extra/chi_nu_susceptibility_bounds.tex:342`, eq. `chinu-law`; `:540`,
eq. `continuation-axiom`):

```
ν_eff(x,t) = ν_OPH(x,t) + χ_can · S_coh^can(x,t)
                        = ν_OPH(x,t) + χ_eng · S_coh^eng(x,t)
```

with charts related by `χ_eng = χ_can/N_coh`, `S_coh^eng = N_coh·S_coh^can`,
`N_coh = ε_sub·u_stored/u₀` (`:547, :516, :508`). Because
`χ_eng·S_coh^eng = χ_can·S_coh^can`, the engineering chart is an exact
rescaling with no independent content — confirmed by the OPH side
(`ANS:/guide` "The Susceptibility Coefficient"). We work in the **canonical
chart** throughout: the physics sits entirely in χ_can (fixed by the Tier-C
branch) and S_coh^can (measured, §3.2).

> **Tier structure upgrade (2026-07-06).** The July paper pass splits the old
> Tier B in two (`:319–351`): **Tier B0** — a *finite source theorem*: under
> the named hypothesis **Scalar Edge-Center Exhaustion** (SEE), every
> nondegenerate self-reading material source is forced into the same scalar
> register the dark-sector collar prices (screen paper `:817–840`), and the
> weak-field response then has the *unique* linear form above (`:842–864`) —
> so the **form** of the law is now derived on the branch, not merely
> declared; **Tier B1** — the response law with χ still unassigned. The
> conditionality is thereby concentrated into SEE + the Tier-C branch.

### 1.4 The coefficient under test (Tier C)

Granting the dark-sector collar lemmas **L0–L7** (L0 the named icosahedral-shape clause, added in v6.1)
(`OPH:/extra/chi_nu_susceptibility_bounds.tex:1021–1210`):

```
0.9343006394893864 ≤ χ_can ≤ 1          (cor. chi-can-band, :1170, under L1–L6)
χ_can = e^(−P/24) = 0.9343006394893864  (cor. chi-can-exact, :1199, adds L7)
```

**This band is the falsification target.** It is *conditional*, and since the
July pass the conditionality is precise: L2–L4 are now imported theorems from
the screen paper **under SEE** (scalar-channel exhaustion / same-register
commutation); L5 is a declared Poisson branch; L6 fixes the scalar-weighted
reserve mean to P/24; **L7 (new)** is the *uniform product-thickening branch*
whose slice-wise reserve-unbiasedness is exactly what licenses the exact value
(screen paper `:1300–1411`, with a receipt ledger `:1475–1492` forbidding
exact-value claims without it — and an explicit remark that uniformity is
*stronger* than the trace condition). The dark-matter paper's Correction Audit
(`OPH:/cosmology/oph_dark_matter_paper.tex:2304–2338`) honestly tabulates that
e^(−P/24) sits between the binned-RAR and common-empirical-a₀ preferred
values and cannot reach the latter without ~13 % more reserve. The experiment
tests whether the substrate's response is consistent with χ_can anywhere in
[0.9343, 1].

> **Machine-checked status (v0.2.2, proof-chain v4).** Both the *digits* and
> the *conditional structure* above are now Lean theorems: e^(−P/24) =
> 0.9343006… to 9 digits (`proof_chain/formal/OPHProofChain/PBranches.lean`),
> and L-clause unbiasedness ⇒ exactly e^(−P/24), with the [e^(−P/24), 1]
> Jensen band under the weaker mean condition
> (`proof_chain/formal/OPHProofChain/CollarGate.lean`). The conditionality of
> this target therefore rests *entirely* on the L-clauses themselves. Nothing
> about the band or the falsification target moved.

### 1.5 The force law

Planar response theorem
(`OPH:/extra/chi_nu_susceptibility_bounds.tex:1311–1345`, eq. `force-law` at `:1325`):

```
F_χ = C_geom · A_perp · Δν ,   Δν ≡ χ_can·ΔS_coh^can ,
ΔS_coh = (S_coh)_bottom − (S_coh)_top          (:1313, :1343)
```

> **Derivation status (disclosed at import).** `force-law` is not derived from
> local dynamics. It inserts the continuation into the weak-field
> effective-density identity `ρ_A = −(1/4πG)∇·[(ν−1)g_b]`
> (`OPH:/cosmology/oph_dark_matter_paper.tex:835–841`) — an exact rewriting of
> Poisson's equation — and **reads the resulting phantom mass as a weight
> change of the device itself**. That attribution is a postulate, conceded by
> the OPH side ("the local force is a continuation, not derived"; Document B
> G5). Its lever is transparent: a step Δν across the faces is equivalent to a
> phantom surface density σ = Δν·g/(4πG) ≈ 11.7 kg m⁻² per Δν = 10⁻⁹. The
> experiment *tests* the attribution; nothing here assumes it.
> *(Status note, v0.2.2: the two derived steps around the postulate are now
> machine-checked — the effective-density identity as exact bookkeeping and
> the thin-device integration to `force-law`
> (`proof_chain/formal/OPHProofChain/DarkSector.lean`: `phantom_bookkeeping`,
> `thin_device_force`), and σ as the interval (11.6, 11.8) kg m⁻²
> (`…/EnergyCage.lean`). The **attribution itself remains the postulate under
> test** — unchanged.)*

Engineering construction variable, for cross-checks only
(`:1376`, eq. `Gamma-definition`): `ΔS_coh^eng = Γ_eff·(u/u₀)`, 0 ≤ Γ_eff ≤ 1.
The paper now also carries **source-lift falsifiers** (`:1696–1719`) — five
operational tests any material lift claim must survive (record-shuffled dummy,
relabeling invariance, register identity, receipt-zero vs force, signed-flip
tracking) — adopted implicitly by our run matrix (Document C Part 5).

### 1.6 Null-result bound formula (OPH's own)

A null at force sensitivity F_min over area A
(`OPH:/extra/chi_nu_susceptibility_bounds.tex:1651`, eq. `null-bound-general`):

```
Δν ≤ Δν_min ≡ F_min / (C_geom · A)
χ_can · ΔS_coh^can ≤ Δν_min                    (always)
χ_can ≤ Δν_min / ΔS_coh^can                    (given the §3.2 bridge)
```

A back-solved χ_can bound < 0.9343 excludes the Tier-C band (§1.4).

### 1.7 Null conditions on the scalar (the exemption clause)

Matter without observer structure gives zero scalar, hence zero force
(`OPH:/extra/chi_nu_susceptibility_bounds.tex:568–580`, prop. `chi-null-conditions`;
core scalar `:473`, eq. `canonical-core`):

```
S_coh^can = 1_self-read · R_U · P_U · C_U
S_coh^can = 0  if (no self-read) OR (no stable records) OR (no predictive boundary coupling)
```

and such configurations "impose no bound on χ" (`:1668–1680`). Since the July
pass the paper also carries the full **finite coherent-matter source
generator** (`:625–746`): the self-reading subfederation, its scalar-slot
footprint ("not a new field" — a quotient-visible map, descent proof in the
section's Lemma B.6), and the source generator — i.e. the *definition side* of
the ΔS bridge is now first-party paper content. **This clause
is load-bearing**: it is the only thing exempting the active coupon from the
existing null corpus of precision-weighed piezo/ferroelectric devices. OPH
defines self-read operationally — a **self-bounded read-write substrate**
(the same ports emit and read; H1/H2 device bounds,
`OPH:/extra/thinking_as_patch_net_fixed_point_search.tex:2218–2234`; observer
tuple with records and checkpoints,
`OPH:/paper/screen_microphysics_and_observer_synchronization.tex:94–148`) —
and never as a material property. §3.5 therefore uses the read-write loop as
the operational criterion, and the dummy differs from the active coupon in
exactly that loop (§3.6).

### 1.8 Terrestrial baseline

On Earth `g_b/a₀ ~ 10¹¹`, so ν_OPH is pinned to unity (suppression is
hyper-exponential in the activation law) and the ordinary OPH dark sector
reads **null** on a tabletop
(`OPH:/extra/chi_nu_susceptibility_bounds.tex:423–426`; activation law and
limits: `OPH:/cosmology/oph_dark_matter_paper.tex:681–751`). The χ_ν
continuation is tested against a null baseline as a separate, added effect —
it is **not** a prediction of the recovered OPH core, which leaves χ_ν unfixed
(`OPH:/extra/chi_nu_susceptibility_bounds.tex:319–325`, Tier A).

### 1.9 Conservation-law constraints (disclosed prior physics)

Independent of any apparatus, a vertical force controlled by an internal
switchable state obeys `F = −∇E_state`, so `E_state = ΔM·Φ_N(z) + const` with
`ΔM = F/g`. Two exhaustive cases
(full derivation: `proof_chain/OPH_CORE_MINIMAL_PROOF_CHAIN.md` §5 —
theorem-form since proof-chain v3, with the numbers below as machine-checked
intervals: `proof_chain/formal/OPHProofChain/EnergyCage.lean`):

- **height-independent toggle cost** ⇒ an ACTIVE-on / rise / ACTIVE-off /
  descend cycle extracts F·h per pass — perpetual motion. *What the cycle
  theorems themselves force* (proof-chain v6.1, after the adversarial
  audit's F15): a ledger entry at the scale of **realized cycle work** —
  ΔM·g·Δh ≈ 0.55 J per metre of stroke at the design point; ≈ 0 for the
  balance protocol at fixed height.
- **the G10-convention** *(named pricing hypothesis of this decision
  layer, not a consequence of the cycle theorems)*: each ACTIVE toggle is
  priced as the full infinity-referenced interaction transaction
  |ΔM·Φ_N| ≈ **3.5 MJ for the 56 gf design point** (Φ_N ≈ −6.3×10⁷ J kg⁻¹)
  — ~1 kg-TNT-scale heat/work per state change, never observed in any
  piezo. (Pricing genuine source *creation* relativistically would give
  ΔM·c² ≈ 5×10¹⁵ J instead; the convention adopts the interaction-energy
  reading as the audit scale.) Under this convention a battery-powered
  coupon (E_batt ~ 3.6×10⁴ J) can source at most
  **χ·ΔS ≲ 1.1×10⁻¹¹** (≈ 0.58 gf) per toggle.
  > *Erratum (2026-07-07):* previously printed "≲ 1×10⁻¹¹ (≈ 0.5 gf)". The
  > interval-checked value is (1.02–1.03)×10⁻¹¹ (0.575–0.578 gf), so the old
  > print understated the coupon ceiling by ≈ 2.5 % — the unsafe direction for a
  > discrimination bound. Machine-checked:
  > `proof_chain/formal/OPHProofChain/LedgerNumerics.lean`
  > (`battery_coupon_bounds`).

Consequence, agreed by both sides at lock: a NULL is the theoretically
expected outcome and still yields the §1.6 bound; a genuine DETECT with
transport cycles must reconcile its logs against the theorem-grade minimum
(realized cycle work), and carries an extraordinary-evidence burden against
the G10-convention audit scale — which the Part 5 conjunction and the
energy-budget logging (Document C Part 7) are designed to meet. The
convention is a *named hypothesis of the decision layer* (it can be
contested without touching any theorem); the cycle identities and the
arithmetic are machine-checked. This section calibrates interpretation; it
does **not** alter the decision rule.

---

## Part 2 — The v3 design figures (reference targets)

From `HOVER:/` — orientation only, we do **not** build the v3 board:

| Quantity | Value | Source |
|---|---|---|
| v3 projected area A_perp | 0.063 m² | HOVER:/docs/explainer.md:120 |
| v3 hover threshold Δν | 3.4×10⁻¹⁰ | HOVER:/docs/explainer.md:122 |
| v3 design target Δν | ≥ 1.0×10⁻⁹ | HOVER:/docs/explainer.md:123 |
| Required ΔS_coh^can (v3) | ≥ 3.7×10⁻¹⁰, design ≈ 1.0×10⁻⁹ | HOVER:/docs/theory-assumptions.md:55,61 |
| Force at design target | ≈ 7.25 N (≈ 739 gf) | HOVER:/docs/explainer.md:125–126 |
| Formal success criteria | A ≥ 0.063 m², M ≤ 0.25 kg, Δν ≥ 1×10⁻⁹, F ≥ 7.2 N | HOVER:/docs/acceptance.md |
| OPH force table (Δν → F) | 1e-10 → 0.72 N · 3.5e-10 → 2.54 N · 1e-9 → 7.25 N · 1e-8 → 72.5 N | HOVER:/docs/concept.md |

`HOVER:/docs/acceptance.md` accepts Δν "measured **or inferred**" — our
balance measures F and infers Δν via §1.5, satisfying that criterion.

---

## Part 3 — Inputs from the OPH side (agreed 2026-06-03; confirm at lock)

> These are the only free choices; Part 4 is computed from them. If a field
> cannot be filled, write "UNDEFINED" (see §4.7).

### 3.1 Active substrate — the self-reading PoC

The coupon is an **active, self-reading PoC** (`ANS:/answer` §3.1–3.2;
`ANS:/guide` "The First Real PoC"), not a passive material stack:

- battery-powered nonmagnetic plate (quartz / alumina / glass-ceramic /
  sapphire / insulated aluminum);
- 4–12 **same-port or tightly co-located TX/RX piezo (or optical) ports**,
  **top and bottom zones read separately**;
- onboard MCU + logger + battery; **no cables during weighing**;
- BiFeO₃ is an *optional* coherent insert, not the active ingredient — the
  read→record→predict→repair loop is what puts the coupon on the signal
  branch. (The TDK piezo "proxy stage" of the original BOM is checkout-only,
  `HOVER:/docs/build-tutorial.md:256`; it lacks the loop and is not a test
  article.)
- Projected active area **A = 4.8×10⁻³ m²** (one zone, ≈ 80×60 mm), confirmed
  by the OPH side (`ANS:/answer` §3.1). Predicted force scales with A (§1.5),
  so coupon scale is on-protocol — the OPH prototype sequence itself begins
  "1. Single-zone coupon" (`HOVER:/docs/architecture.md`).

| Coupon (at Δν = 1×10⁻⁹) | A [m²] | Predicted F | gf |
|---|---|---|---|
| full board (reference only) | 0.063 | 7.2 N | 735 |
| **one zone ≈ 80×60 mm (baseline)** | 4.8×10⁻³ | 0.55 N | 56 |
| small coupon 20×20 mm | 4.0×10⁻⁴ | 0.046 N | 4.7 |

The Milestone-1 build of the self-reading object (rings, ×120 RX chain,
coupling-matrix logging) is specified in [`build/`](../build/README.md).

### 3.2 Primary prediction input — the coherence contrast is measured

- **ΔS_coh^can is measured, not pre-predicted** (`ANS:/answer` §1, §3.4): the
  coupon reads S_top^can and S_bottom^can from its own port records in the
  mandatory pre-test (§3.5), giving a **signed** ΔS_coh^can = S_bottom − S_top
  with a commanded sign (ACTIVE+ vs ACTIVE−).
- Magnitude is back-solved from the balance via §1.5; the pre-test fixes
  existence, sign and relative scaling.
- Passive stacks: ΔS_coh^can = 0 (confirmed null branch).

> **⚠ The ΔS-estimator bridge (load-bearing, open — Document B G9).** The test
> assumes the record-derived ΔS_coh^can is the same scalar that enters the
> force law. The OPH side states openly that a null bounds the **product
> χ_ν·ΔS**, and χ_ν alone only if the estimator is accepted (`ANS:/answer`
> §4). The magnitude tension is acknowledged by both sides: a record contrast
> of even ΔS ~ 10⁻⁶ would predict ~500 N on this coupon (F ≈ 5.14×10⁸·ΔS), so
> the bridge cannot be a literal identity at the magnitudes a healthy
> self-reading device naturally produces. The experiment therefore tests
> **sign, scaling and branch**, and back-solves a bound.

### 3.3 Coefficient used

- χ_can = **0.9343006394893864** (§1.4), confirmed by the OPH side
  (`ANS:/guide` "The Susceptibility Coefficient").
- Coupon coefficient: **F_χ ≈ 5.14×10⁸ · ΔS_coh^can N** (= C_geom·A·χ_can at
  A = 4.8×10⁻³ m²). Scale: ΔS = 10⁻⁹ → 0.514 N (52 gf); 10⁻¹¹ → 0.52 gf; a
  1 g apparent change ⇔ ΔS ≈ 1.9×10⁻¹¹.

### 3.4 Engineering-chart cross-check — not used

The OPH side works in the canonical chart (§1.3); the engineering-chart fields
stay empty. Retained sanity rail: the operating mode is static pre-stress, so
any stored density is elastic, `u = σ²/(2E)`
(`OPH:/extra/chi_nu_susceptibility_bounds.tex:1521`). For quartz/LiNbO₃
(E ≈ 70–200 GPa) at safe tens of MPa, **u ~ 10³–10⁴ J m⁻³** (e.g. 30 MPa on
100 GPa → 4.5×10³); even near the brittle limit u ≲ 10⁵ J m⁻³. Any input
implying more stored density than the material can hold is out of bounds
before testing.

### 3.5 Self-read criterion (REQUIRED — the §1.7 gate, resolved as case ii)

The active element **is** the self-reading system (`ANS:/answer` Q2); passive
BiFeO₃ does not satisfy self-read. Operational property — the **self-read
loop** `drive → self-read → record → predict boundary → repair/update →
repeat`, gated by `S_coh^can = 1_self-read·R_U·P_U·C_U` (all four nonzero):

- **1_self-read** — each zone drives and senses its own mode through the same
  port or a fixed co-located TX/RX pair;
- **R_U** — repeated runs reproduce the records within preregistered tolerance;
- **P_U** — records at cycle *t* predict held-out boundary readouts better
  than shuffled records / the dummy;
- **C_U** — port data show repeatable, state-dependent coherent structure
  (implemented check: the coupling matrix stands above **both** the shuffled
  and the off-resonance control, `build/electronics.md`).

Present in the active coupon by design (firmware logs the receipt onboard);
absent in the dummy (§3.6); tunable (ACTIVE± commands opposite signs of ΔS;
drive amplitude / pre-stress vary the stored state, §3.7). **The pre-test
passing this gate is a precondition for any weighing** (Document C, R-pre): a
null on a coupon that failed the gate is uninformative — OPH predicts null
there too.

### 3.6 Matched dummy specification

Artifact-control object (not a mass baseline — Document C §3.1): matches the
active coupon in mass, CoM, geometry, coating/emissivity, thermal mass,
battery SoC, electrical draw, shielding, wiring and state schedule, and lacks
**only** a valid self-read loop — broken via resistive loads, phase-scrambled
drive, damped transducers, or record-shuffled firmware (`ANS:/answer` §3.3).
Magnetic hardware matched; magnetic bias never toggles inside a comparison
(Document C §3.2).
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

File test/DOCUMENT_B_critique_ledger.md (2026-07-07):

# Document B — Open Questions & Credit Ledger

**χ_ν coherent-matter lift test · what remains open, what is settled, what stands regardless**

| | |
|---|---|
| Status | OPEN ledger — shared working document (no longer a held critique) |
| Version | 0.3.1 (2026-07-07, second refresh: counts and open items updated to proof-chain v7 — the earlier 0.3 row said "v4" over v4-era counts; 0.3, 0.2 and the v0.1 critique ledger are in git) |
| Companion to | `DOCUMENT_A_prediction_ledger.md`, `DOCUMENT_C_run_matrix_and_error_budget.md` (this directory), `proof_chain/OPH_CORE_MINIMAL_PROOF_CHAIN.md` |

> Path shortcuts (`OPH:/`, `HOVER:/`, `ANS:/…`) are defined in Document A.

> **2026-07-06 — OPH-side audit response received** (`proof_chain/AUDIT_RESPONSE.md`, via
> PR): it grades every gap in this ledger, accepts nearly all of them as valid,
> and answers with a July paper pass that adds theorem surfaces, receipts and
> scope boundaries. Our verification of that response (all pin-cites checked):
> `proof_chain/AUDIT_RESPONSE_REVIEW.md`. Dispositions below updated accordingly.

> **2026-07-07 — proof-chain v4: the `formal/` Lean tree completes.** The whole
> mathematical side of the chain is now machine-proven in one tree
> (`proof_chain/formal/`: 29 modules as of v7, environment-swept — **0
> `sorry`** — including an attributed copy of the OPH Lean core with its three
> declared `sorry`s discharged). **No physics grade changed and nothing in the
> decision rule moved**; the v0.3 edits below are status/credit refreshes only
> (G6, G9, G10 pointers; V2, V3, V6 credits; Part 5 item 3 executed). Details:
> `proof_chain/OPH_CORE_MINIMAL_PROOF_CHAIN.md` (v4), `proof_chain/formal/README.md`,
> `proof_chain/formal/RESULTS.md`.

## Why this document changed character

Version 0.1 was written 2026-06-02 as a *held* critique — nine logical gaps
(G1–G8, later G9), firewalled so they would only be argued from after a
confirmed null. It is now mostly a historical success story: the OPH side's
2026-06-03 answers closed or openly acknowledged nearly everything, the
engineering prose adopted the conditional framing the ledger asked for, and
the 2026-07-05 verification pass moved the remaining derivation-status caveats
*into Document A itself*, disclosed at the point of import (A §1.4, §1.5,
§1.9). There is nothing left to hold back: what remains are **two open
questions both sides share**, and a credit list. On a NULL outcome, this
document frames the discussion section; on a DETECT it records what a
detection must overturn.

## Part 1 — Disposition of the original gaps
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

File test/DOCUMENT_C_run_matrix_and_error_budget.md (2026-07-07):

# Document C — Run Matrix, Measurement Method, and Error Budget

**χ_ν coherent-matter lift test · companion to Document A**

| | |
|---|---|
| Status | DRAFT — not yet locked |
| Version | 0.2.1 (2026-07-07: Part 7 energy-budget logging now cites the named G10-convention audit scale per proof-chain v6.1/v7; 0.2 of 2026-07-05 and v0.1 are in git) |
| Companion to | `DOCUMENT_A_prediction_ledger.md` (governs interpretation) |
| Governs | apparatus sensitivity F_min, the run sequence, and the analysis |

> Path shortcuts (`OPH:/`, `HOVER:/`, `ANS:/…`) are defined in Document A.
> The primary method is a **no-cables ABBA** comparison of ACTIVE± against a
> power-matched SHAM state **within one self-contained, battery-powered,
> self-reading PoC** (A §3.1). The dummy is an artifact control, never the
> mass baseline. A balance null bounds χ_ν·ΔS — χ_ν alone only given the
> ΔS-estimator bridge (A §3.2).

## Purpose

Document A leaves the apparatus force resolution F_min symbolic. This document
fixes F_min for a specific balance and method, derives the detection floor,
and specifies the run sequence and analysis. Nothing physical originates here
except the apparatus model and the statistics.

---

## Part 1 — Imported quantities (no new physics here)

| Symbol | Value | Source |
|---|---|---|
| C_geom = g²/(4πG) | 1.146637×10¹¹ N m⁻² | A §1.1 (← `OPH:/extra/chi_nu_susceptibility_bounds.tex:1347–1361`) |
| Force law | F = C_geom·A·Δν, Δν = χ_can·ΔS_coh^can | A §1.5 |
| Detection floor | Δν_min = F_min/(C_geom·A) | A §4.2 / §1.6 |
| χ_can null bound | χ_can ≤ Δν_min/ΔS_coh^can (given the bridge) | A §4.4 |
| Theorem floor under test | χ_can ≥ 0.9343006394893864 | A §1.4 |
| Coupon area (baseline) | A = 4.8×10⁻³ m² (one zone, 80×60 mm) | A §3.1 |
| Conservation-law priors | NULL expected; toggle-energy logging required | A §1.9 |
| Controls / data per run | control matrix + data list | `HOVER:/docs/acceptance.md`; Part 7 |
| Safety | HV, brittle substrate, magnets | `HOVER:/docs/safety.md` |

---

## Part 2 — The chosen instrument
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

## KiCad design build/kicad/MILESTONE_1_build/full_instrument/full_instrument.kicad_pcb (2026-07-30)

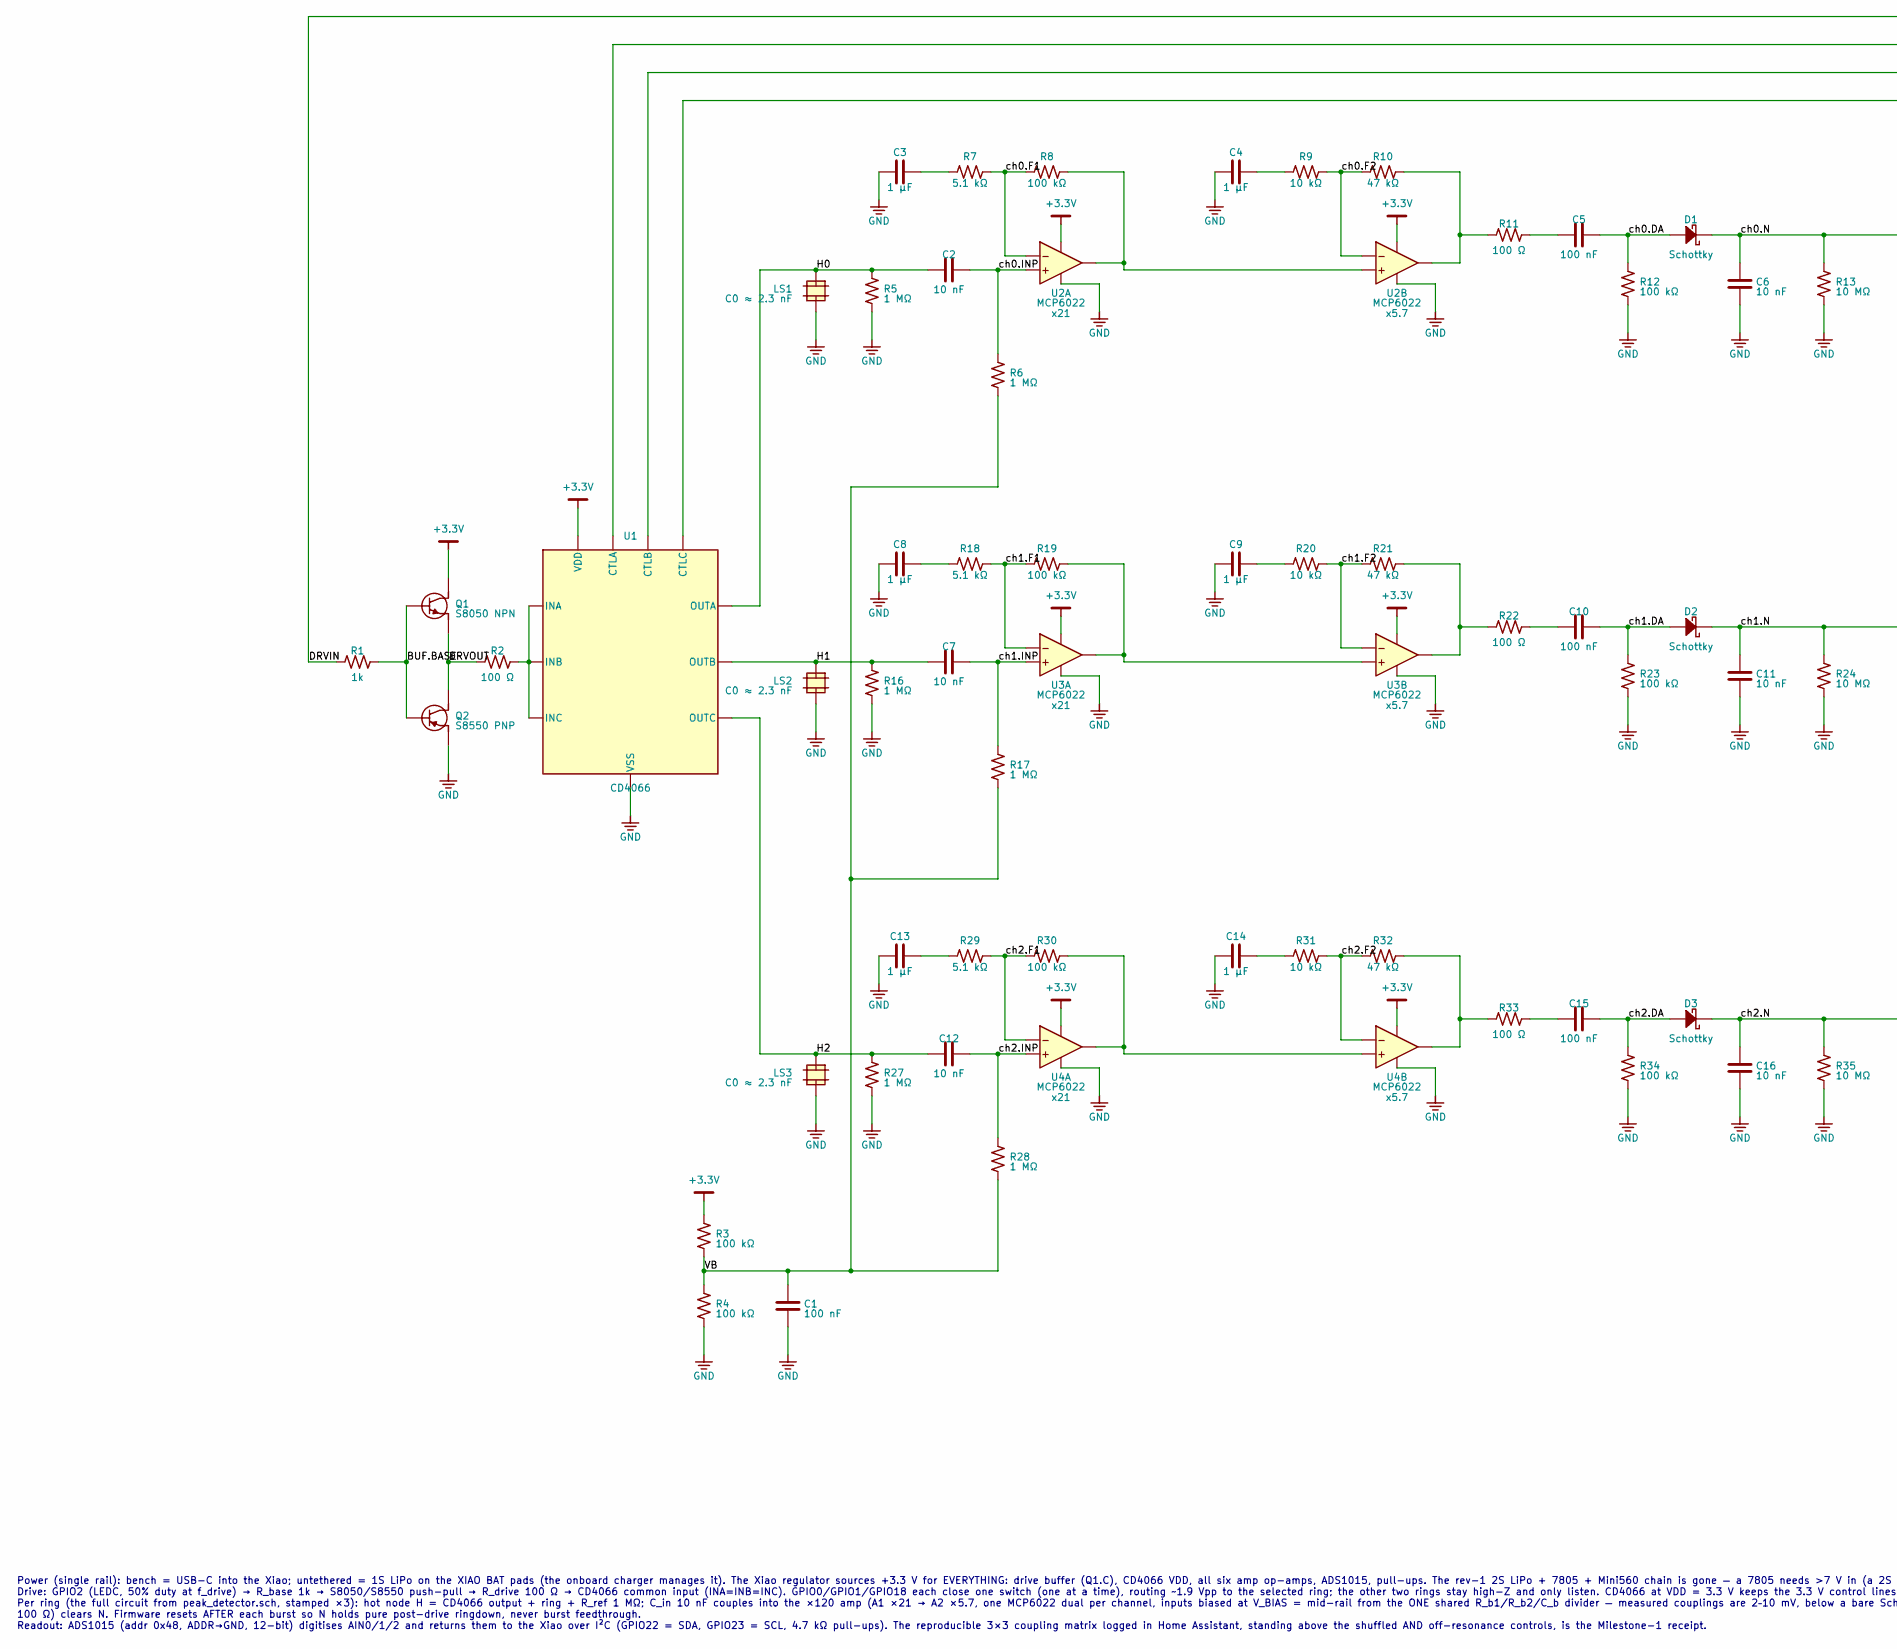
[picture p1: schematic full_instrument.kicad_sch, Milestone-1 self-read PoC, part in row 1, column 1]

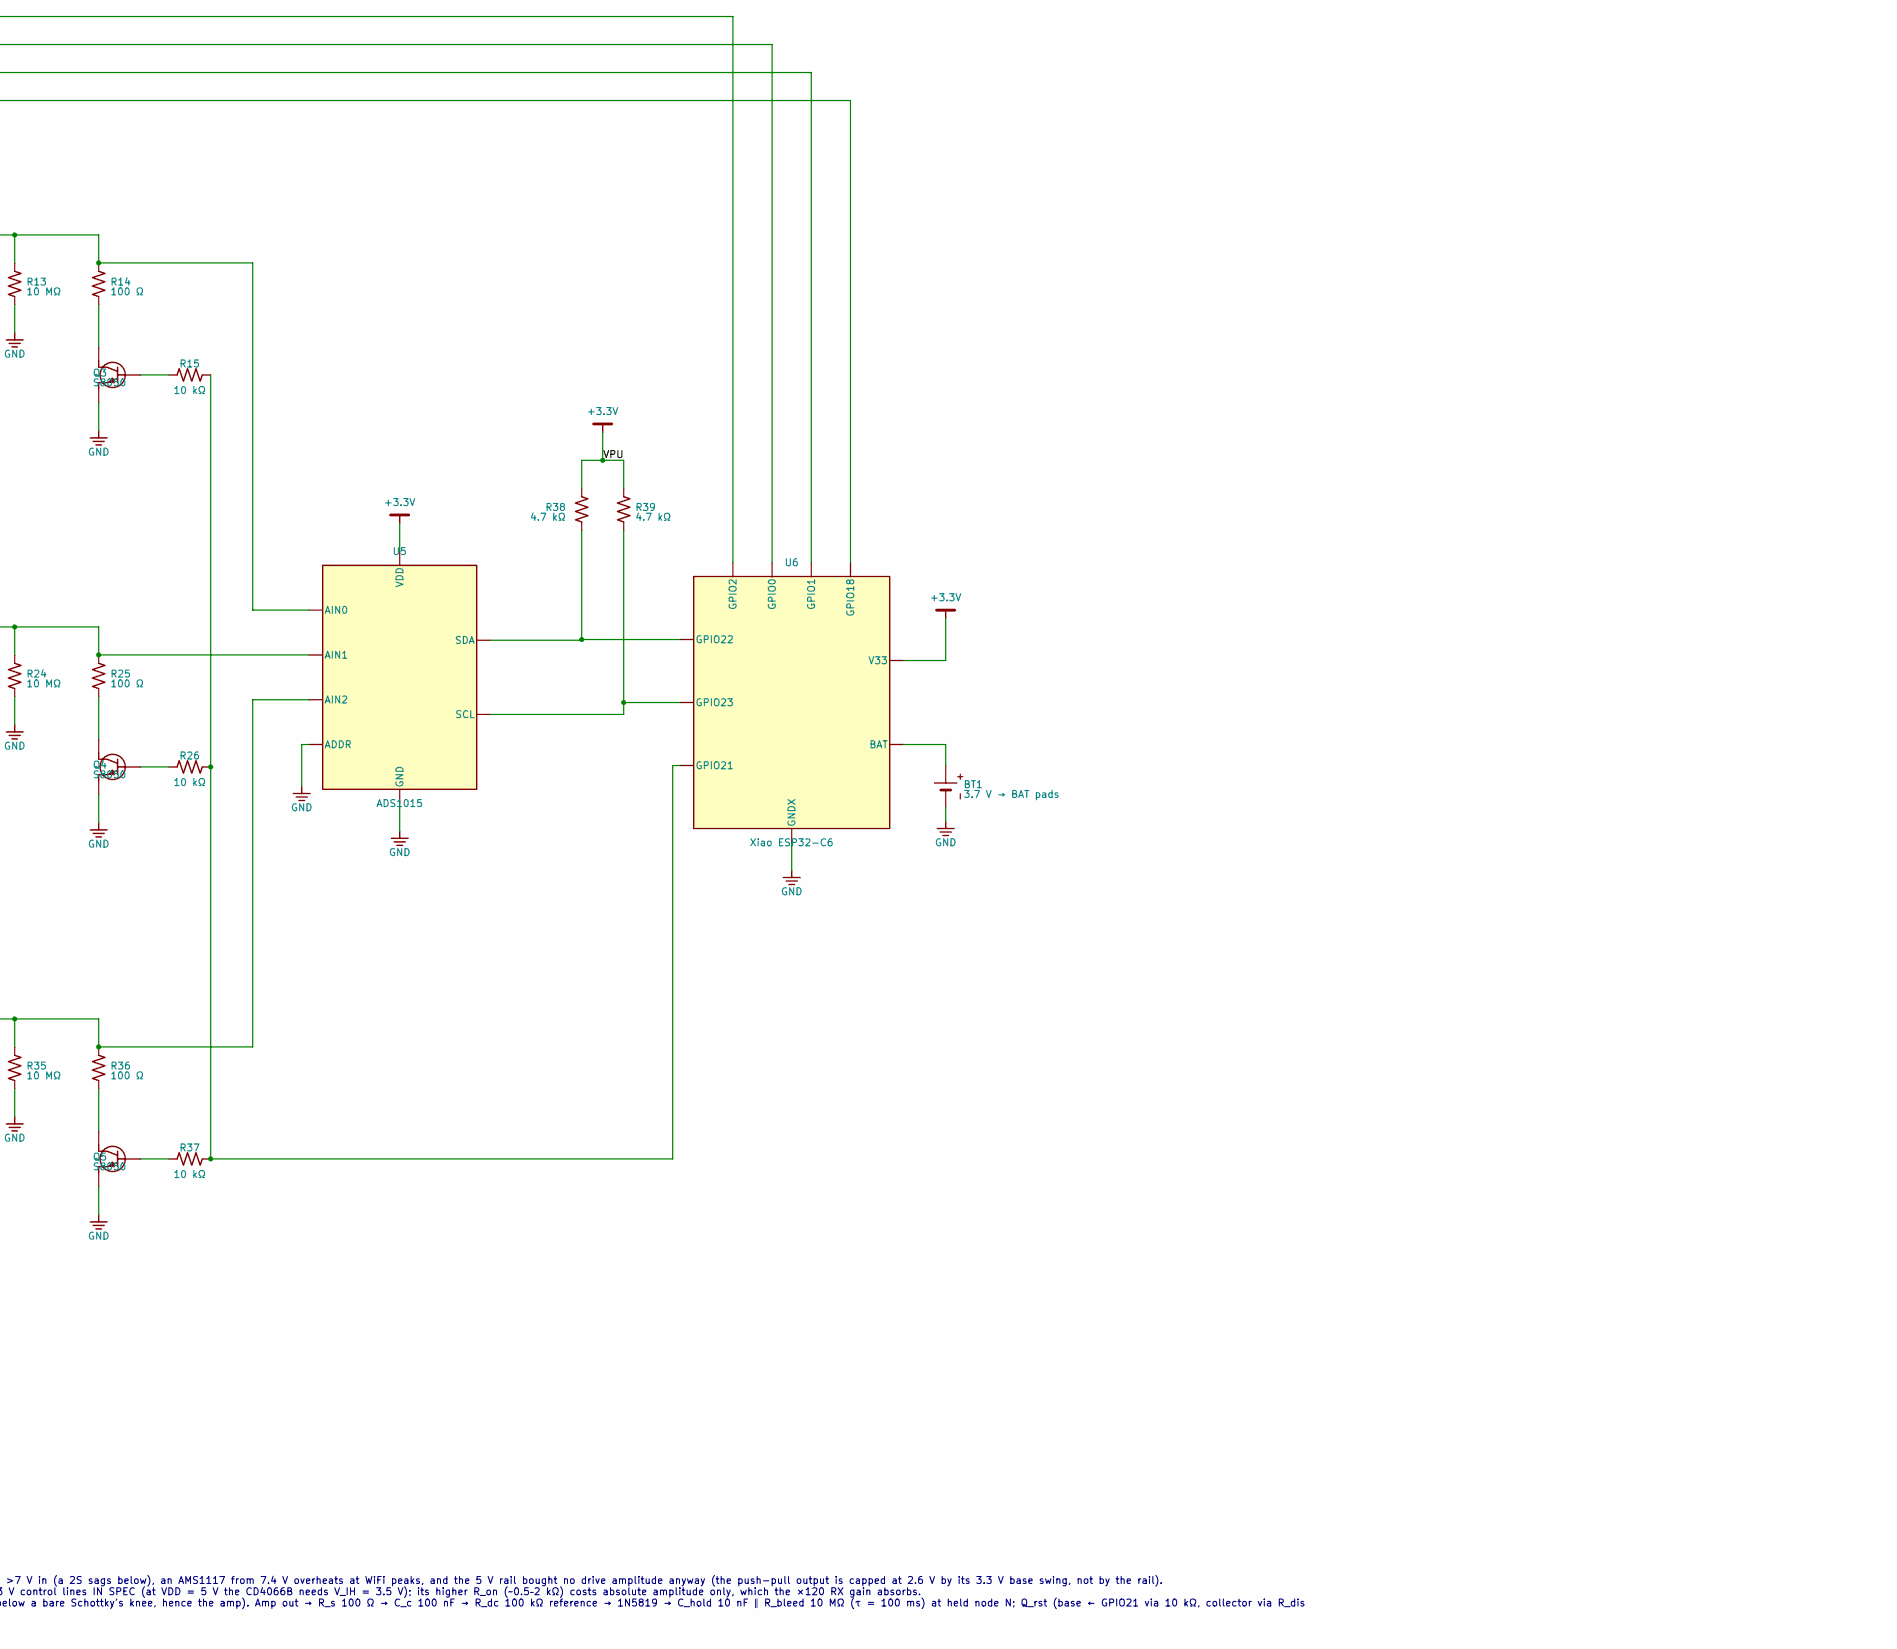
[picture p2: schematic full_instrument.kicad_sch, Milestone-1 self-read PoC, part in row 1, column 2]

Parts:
BT1: 3.7 V → BAT pads; BatteryHolder_MPD_BH-18650-PC
C1, C5, C10, C15: 100 nF; C_1206_3216Metric
C2, C6, C7, C11, C12, C16: 10 nF; C_1206_3216Metric
C3, C4, C8, C9, C13, C14: 1 µF; C_1206_3216Metric
D1, D2, D3: Schottky; D_1206_3216Metric
LS1, LS2, LS3: C0 ≈ 2.3 nF; JST_PH_B2B-PH-K_1x02_P2.00mm_Vertical
Q1: S8050 NPN; SOT-23
Q2: S8550 PNP; SOT-23
Q3, Q4, Q5: S8050; SOT-23
R1: 1k; R_1206_3216Metric
R2, R11, R14, R22, R25, R33, R36: 100 Ω; R_1206_3216Metric
R3, R4, R8, R12, R19, R23, R30, R34: 100 kΩ; R_1206_3216Metric
R5, R6, R16, R17, R27, R28: 1 MΩ; R_1206_3216Metric
R7, R18, R29: 5.1 kΩ; R_1206_3216Metric
R9, R15, R20, R26, R31, R37: 10 kΩ; R_1206_3216Metric
R10, R21, R32: 47 kΩ; R_1206_3216Metric
R13, R24, R35: 10 MΩ; R_1206_3216Metric
R38, R39: 4.7 kΩ; R_1206_3216Metric
U1: CD4066; SOIC-14_3.9x8.7mm_P1.27mm
U2, U3, U4: MCP6022; SOIC-8_3.9x4.9mm_P1.27mm
U5: ADS1015; TSSOP-10_3x3mm_P0.5mm
U6: Xiao ESP32-C6; XIAO-ESP32-C6-SMD

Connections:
+3.3V: Q1.2 (C), R3.1 (a), R38.1 (a), R39.1 (a), U1.14 (VDD), U2.8 (V+), U3.8 (V+), U4.8 (V+), U5.8 (VDD), U6.12 (V33)
/BUF.BASE: Q1.1 (B), Q2.1 (B), R1.2 (b)
/DRVIN: R1.1 (a), U6.3 (GPIO2)
/DRVOUT: Q1.3 (E), Q2.3 (E), R2.1 (a)
/H0: C2.1 (a), LS1.1 (a), R5.1 (a), U1.2 (OUTA)
/H1: C7.1 (a), LS2.1 (a), R16.1 (a), U1.4 (OUTB)
/H2: C12.1 (a), LS3.1 (a), R27.1 (a), U1.9 (OUTC)
/VB: C1.1 (a), R3.2 (b), R4.1 (a), R6.2 (b), R17.2 (b), R28.2 (b)
/ch0.DA: C5.2 (b), D1.2 (A), R12.1 (a)
/ch0.F1: R7.1 (a), R8.2 (b), U2.2 (-)
/ch0.F2: R9.1 (a), R10.2 (b), U2.6 (-)
/ch0.INP: C2.2 (b), R6.1 (a), U2.3 (+)
/ch0.N: C6.1 (a), D1.1 (K), R13.1 (a), R14.1 (a), U5.4 (AIN0)
/ch1.DA: C10.2 (b), D2.2 (A), R23.1 (a)
/ch1.F1: R18.1 (a), R19.2 (b), U3.2 (-)
/ch1.F2: R20.1 (a), R21.2 (b), U3.6 (-)
/ch1.INP: C7.2 (b), R17.1 (a), U3.3 (+)
/ch1.N: C11.1 (a), D2.1 (K), R24.1 (a), R25.1 (a), U5.5 (AIN1)
/ch2.DA: C15.2 (b), D3.2 (A), R34.1 (a)
/ch2.F1: R29.1 (a), R30.2 (b), U4.2 (-)
/ch2.F2: R31.1 (a), R32.2 (b), U4.6 (-)
/ch2.INP: C12.2 (b), R28.1 (a), U4.3 (+)
/ch2.N: C16.1 (a), D3.1 (K), R35.1 (a), R36.1 (a), U5.6 (AIN2)
GND: BT1.2 (-), C1.2 (b), C3.2 (b), C4.2 (b), C6.2 (b), C8.2 (b), C9.2 (b), C11.2 (b), C13.2 (b), C14.2 (b), C16.2 (b), LS1.2 (b), LS2.2 (b), LS3.2 (b), Q2.2 (C), Q3.3 (E), Q4.3 (E), Q5.3 (E), R4.2 (b), R5.2 (b), R12.2 (b), R13.2 (b), R16.2 (b), R23.2 (b), R24.2 (b), R27.2 (b), R34.2 (b), R35.2 (b), U1.7 (VSS), U2.4 (V-), U3.4 (V-), U4.4 (V-), U5.1 (ADDR), U5.3 (GND), U6.13 (GNDX)
unnamed: BT1.1 (+), U6.23 (BAT)
unnamed: C3.1 (a), R7.2 (b)
unnamed: C4.1 (a), R9.2 (b)
unnamed: C5.1 (a), R11.2 (b)
unnamed: C8.1 (a), R18.2 (b)
unnamed: C9.1 (a), R20.2 (b)
unnamed: C10.1 (a), R22.2 (b)
unnamed: C13.1 (a), R29.2 (b)
unnamed: C14.1 (a), R31.2 (b)
unnamed: C15.1 (a), R33.2 (b)
unnamed: Q3.1 (B), R15.1 (a)
unnamed: Q3.2 (C), R14.2 (b)
unnamed: Q4.1 (B), R26.1 (a)
unnamed: Q4.2 (C), R25.2 (b)
unnamed: Q5.1 (B), R37.1 (a)
unnamed: Q5.2 (C), R36.2 (b)
unnamed: R2.2 (b), U1.1 (INA), U1.3 (INB), U1.8 (INC)
unnamed: R8.1 (a), U2.1 (out), U2.5 (+)
unnamed: R10.1 (a), R11.1 (a), U2.7 (out)
unnamed: R15.2 (b), R26.2 (b), R37.2 (b), U6.4 (GPIO21)
unnamed: R19.1 (a), U3.1 (out), U3.5 (+)
unnamed: R21.1 (a), R22.1 (a), U3.7 (out)
unnamed: R30.1 (a), U4.1 (out), U4.5 (+)
unnamed: R32.1 (a), R33.1 (a), U4.7 (out)
unnamed: R38.2 (b), U5.9 (SDA), U6.5 (GPIO22)
unnamed: R39.2 (b), U5.10 (SCL), U6.6 (GPIO23)
unnamed: U1.13 (CTLA), U6.1 (GPIO0)
unnamed: U1.5 (CTLB), U6.2 (GPIO1)
unnamed: U1.6 (CTLC), U6.11 (GPIO18)

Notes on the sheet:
Power (single rail): bench = USB-C into the Xiao; untethered = 1S LiPo on the XIAO BAT pads (the onboard charger manages it). The Xiao regulator sources +3.3 V for EVERYTHING: drive buffer (Q1.C), CD4066 VDD, all six amp op-amps, ADS1015, pull-ups. The rev-1 2S LiPo + 7805 + Mini560 chain is gone —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

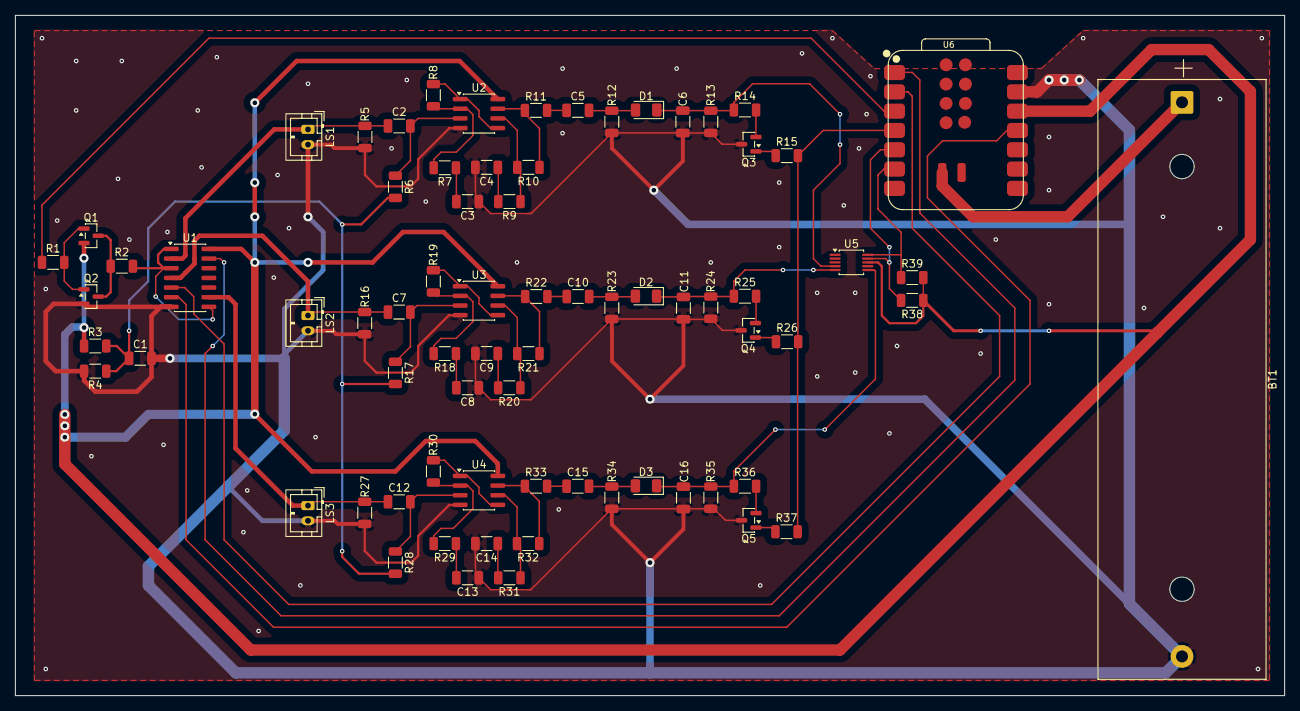
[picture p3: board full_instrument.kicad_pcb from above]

Board: 4 copper layers, 167.0 x 89.5 mm, 73 parts (0 on the bottom side), 53 nets.

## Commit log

2026-07-09 proof chain v9: the slope conjecture falls (T36) + the gap-2 crawl classified (T37)
2026-07-10 proof chain v10: the simulation's findings become theorems — T38 parity splitting (R1; even-ring failure ⟺ single-parity ghost, unconditional), T39 two-power universality (C3 closed: every worldline 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
2026-07-29 add KiCad export
2026-07-30 add PCB
    [controller_power.sch, drive_stage.sch, full_instrument.kicad_pcb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]
2026-07-30 update PCB
    [full_instrument.kicad_pcb]
